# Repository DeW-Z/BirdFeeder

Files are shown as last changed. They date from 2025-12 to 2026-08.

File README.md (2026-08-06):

# BirdFeeder

BirdFeeder is a DIY bullet feeder for progressive reloading presses. Bulk projectiles are placed into the hopper, where the rotating collator plate orients them and feeds them into a drop tube leading to the press.

The project was designed around commonly available hardware, a NEMA 17 stepper motor, 3D-printed components, and a custom motor-control PCB.

## Project Status

BirdFeeder currently has two controller options:

| Option | Status |
| --- | --- |
| Original Controller | Stable and supported |
| Smart Controller | Active development |
| Planetary Gearbox | Beta testing |
| NEMA 23 Version | Beta testing | 

## Original BirdFeeder Controller

The original controller is a simple through-hole PCB that can be assembled using commonly available components.

Its main functions include:

* Adjustable stepper-motor speed
* NEMA 17 motor control
* Break-beam stopping
* Automatic restart when the feed tube clears
* Compact mounting directly on the feeder
* Quiet operation
* Mechanical slipper clutch protection

The original PCB, firmware, print files, and supporting documentation are fully open-source.

PCB manufacturing files are included in the repository and can be uploaded to a board manufacturer such as JLCPCB. These services normally require ordering several boards at once.

I will continue bulk-ordering and selling individual bare PCBs for builders who do not need a full batch. However, I am no longer producing assembled controllers or complete kits based on the original PCB.

Original PCB listing:

https://www.etsy.com/listing/4429151678/bullet-feeder-9mm-bullet-loader

## Smart Controller

The BirdFeeder Smart Controller is the newer ready-to-use controller option.

It uses an ESP32-S3 and TMC2209 stepper driver to provide easier setup, improved diagnostics, software-adjustable motor control, and electronic jam detection.

Key features include:

* Local browser-based control
* No mobile app or cloud account required
* Home Wi-Fi or standalone operation
* Physical speed-control knob
* Browser-based speed control
* Break-beam stopping and automatic restart
* StallGuard jam detection
* Adjustable jam sensitivity
* Status and diagnostic information
* Wireless firmware updates
* USB Type-C power input with compatible USB-PD supplies
* Physical start, stop, and direction controls

The controller hosts its own web interface and can function without an active internet connection.

The Smart Controller is still under active development and is not yet open-source. Hardware and firmware files will remain private until the design is further developed and tested.

Complete kits will only be offered with the Smart Controller going forward. Stock may be limited because component and manufacturing costs have increased significantly due to tariffs.

Smart Controller documentation:

[Smart Controller README](Smart%20Controller/README.md)

Smart Controller listing:

https://www.etsy.com/listing/4504139794/bullet-feeder-smart-controller

## High-Torque Testing

The standard BirdFeeder uses a NEMA 17 stepper motor and is intended to run with a reasonable amount of material in the hopper.

Some users have reported motor stalls when loading the hopper with more than approximately 100 projectiles. The exact limit varies based on:

* Projectile weight
* Collator plate design
* Printed-part friction
* Motor current
* Power-supply voltage
* Assembly alignment
* Hopper loading
* Material and print quality

Two higher-torque options are currently being evaluated.

### Planetary Gearbox

A planetary gearbox version is included as an additional MakerWorld print profile.

The gearbox increases output torque while retaining the standard NEMA 17 motor. The tradeoff is reduced output speed, additional printed components, and more mechanical complexity.

This design is currently considered beta. Builders should expect that revisions may be made as more testing and feedback are received.

### NEMA 23 Version

A separate NEMA 23 configuration is also under development.

The larger motor is intended for applications where the standard NEMA 17 does not provide enough torque, including heavier projectile types or higher-capacity configurations.

The NEMA 23 version is also considered beta and is not yet the standard recommended build.

## Hopper Capacity and Printed-Part Safety

Do not use the hopper as long-term bulk storage.

Increasing motor torque does not increase the strength of the printed hopper, mount, housing, or supporting hardware. A gearbox or larger motor may keep the collator moving, but the printed structure still supports the full static and dynamic load.

A printed part may appear to support a heavy load initially and still deform or fail after being stressed for hours, days, or weeks. This is especially important with materials that are susceptible to creep, elevated temperatures, weak layer adhesion, or insufficient wall thickness.

Recommended practices:

* Avoid filling the hopper beyond what is needed for the current loading session.
* Refill the hopper in smaller batches.
* Do not leave a heavily loaded hopper sitting between sessions.
* Use a suitable material and print orientation.
* Use adequate walls, top and bottom layers, and infill.
* Inspect the hopper, mount, motor housing, and fasteners regularly.
* Stop using any part that shows cracking, deformation, loose inserts, or damaged mounting points.

The gearbox and NEMA 23 versions are intended to address torque-related stalls. They should not be interpreted as approval to place unlimited weight in the hopper.

## Files and Documentation

The repository includes:

* Original PCB manufacturing files
* Original controller firmware
* Wiring and assembly documentation
* Smart Controller documentation
* Supporting images and reference material

3D-printable files and print profiles are hosted on MakerWorld:

https://makerworld.com/en/models/1252671-bullet-feeder-reloading-assistant#profileId-1697707

## Open-Source Status

### Currently Open-Source

* Original BirdFeeder mechanical design
* Original controller PCB
* Original controller firmware
* Manufacturing files
* Assembly documentation

### Not Yet Open-Source

* Smart Controller PCB design
* Smart Controller production files
* Smart Controller firmware source

The Smart Controller remains under active development. Its source files may be released later, but no release date is currently being promised.

## Safety

BirdFeeder is a DIY project and should be treated as experimental equipment.

Always inspect wiring, printed parts, motors, power supplies, sensors, and mechanical components before use. Do not operate the system unattended. Stop operation immediately if you notice overheating, damaged wiring, unusual noises, binding, cracked printed parts, or repeated motor stalls.

The builder and user are responsible for verifying that their completed assembly is appropriate for their equipment and intended use.

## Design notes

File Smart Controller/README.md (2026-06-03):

# BirdFeeder Smart Controller PCB

<p align="center">
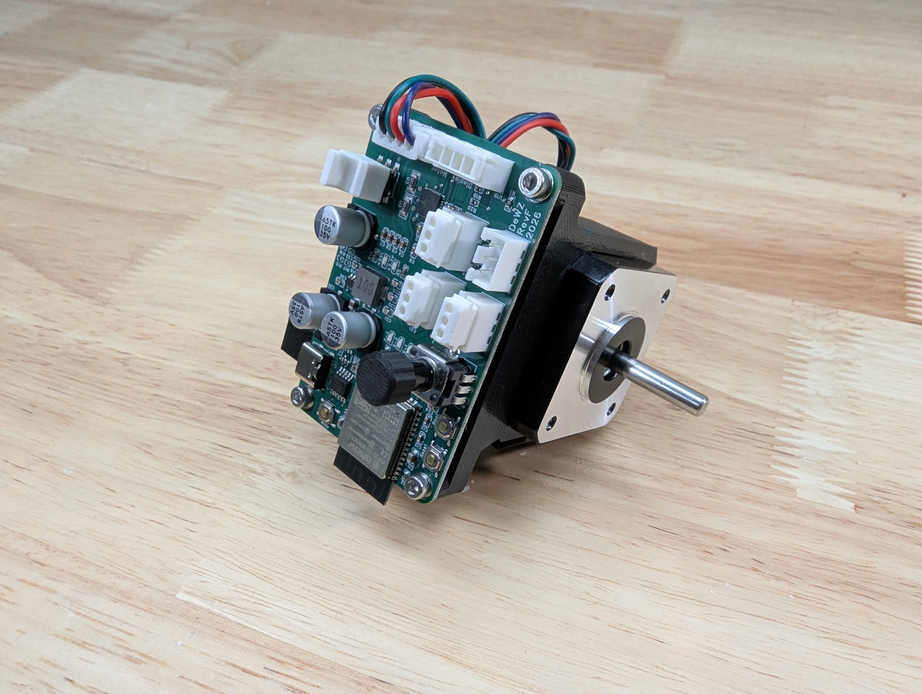
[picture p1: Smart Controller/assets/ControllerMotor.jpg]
BirdFeeder Controller
  
</p>

The **BirdFeeder Smart Controller** is the next generation of stepper motor controller for your BirdFeeder Bullet Feeder. Designed to work with standard USB Type-C power supplies (utilizing up to 20V with compatible PD plugs), it features standard connections for your Break-Beam sensor, Speed Adjuster, and Stepper Motor. 

The biggest change? **Built-in Wi-Fi.** If you are thinking, *"Great, another Wi-Fi device,"* we felt the same way at first! But after helping many people get the original PCB up and running, the biggest hurdle was always downloading complex software (Arduino IDE, drivers, and libraries) just to get started or push a simple update. 

The Smart Controller solves this. **You do not need any development tools or technical experience.** You can configure, control, update, and diagnose your feeder entirely through a simple web page on your phone or computer. It functions 100% offline, no internet access, mobile apps, or cloud accounts required.

Your controller will arrive ready to go, right out of the box!

---

##  Safety & Development Status

> 🛑 **Experimental Hardware Disclaimer:** This controller is currently considered a development and evaluation board. While it includes multiple safety and fault-detection features (such as break-beam stopping, jam detection, motor disable logic, and status monitoring), it has not been certified or evaluated as a commercial safety-rated control system. 
>
> Treat this as experimental hardware. Do not rely upon this controller for life safety, fire prevention, equipment protection, or unattended long-term operation. Do not leave the system operating entirely unattended. Always supervise operation during testing, tuning, and calibration.
>
> **Users are responsible for:** Providing appropriate power protection/wiring, ensuring the mechanism is mechanically safe, and inspecting the system regularly for wear or overheating.

---

##  Table of Contents
1. [Quick Start Guide](#-quick-start-guide)
2. [Main Features](#-main-features)
3. [Smart Controller Mount Installation](#%EF%B8%8F-smart-controller-mount-installation)
4. [Using the Web Control Page](#-using-the-web-control-page)
5. [Troubleshooting & Common Fixes](#-troubleshooting--common-fixes)
6. [Safety & Development Status](#%EF%B8%8F-safety--development-status)
7. [Advanced Technical Reference](#-advanced-technical-reference)

---

##  Quick Start Guide
*Ready to get going? Follow these simple steps to get up and running in less than 5 minutes.*

<p align="center">
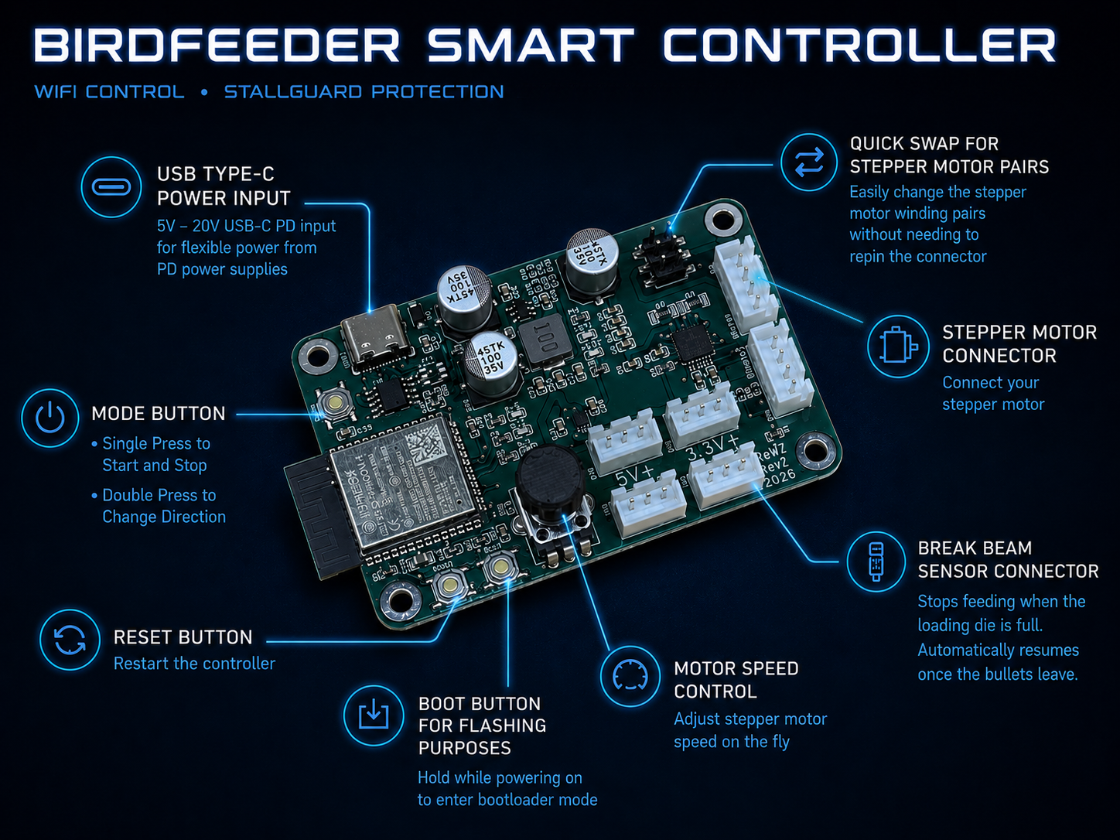
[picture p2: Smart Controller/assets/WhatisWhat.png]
Hardware Layout Map
  
</p>

### Step 1: Plug Everything In
Connect your stepper motor and Break-Beam sensor to the board as shown in the diagram above. Then, plug in your USB Type-C power supply and wait a few seconds for the board to boot up.

### Step 2: Connect to the Setup Wi-Fi
On your phone, tablet, or computer, open your Wi-Fi settings and look for a new network:
* **Network Name (SSID):** `BirdFeeder Setup`
* **Password:** `12345678`

### Step 3: Open the Web Page
Open your favorite web browser (Safari, Chrome, Edge, etc.) and type this exact address into the top URL bar:
**[http://192.168.4.1](http://192.168.4.1)**

### Step 4: Choose Your Mode
The setup screen will guide you through your choice:
* **Home Wi-Fi Mode:** Connect the feeder to your home network so any device in your house can control it. Once connected, your permanent address will be: **[http://birdfeeder.local](http://birdfeeder.local)**
* **Standalone Mode:** Keep it independent. Use this if your feeder is in a garage or workshop without Wi-Fi. You will simply connect directly to the `BirdFeeder Setup` network whenever you want to change settings.

### Don't want to use the Smart Features?
A single press of the "Mode" button will start the motor. A double press with change the direction of travel. Speed can be adjusted manually using the control knob.

---

##  Main Features

* **Easy Web Control Panel:** Control your feeder directly from a simple web page served right from the controller. Includes light and dark themes!
* **Smart Jam Protection:** Powered by built-in StallGuard technology. The controller automatically senses if the motor gets stuck and stops instantly to protect your hardware.
* **Automatic Resume:** Once the die is full of bullets, the motor stops instantly. As soon as the beam is cleared, it starts right back up on its own once the bullets drop down far enough.
* **Wireless Updates:** Easily update your controller's software with a single click right from your browser page—no cords or software installations required.
* **Dual Speed Control:** Switch between using a physical adjustment knob on the box or a digital slider on your phone screen.
* **Local Physical Button:** A single press on the built-in box button starts/stops the motor; a quick double-press reverses the motor direction.

---

##  Smart Controller Mount Installation

<p align="center">
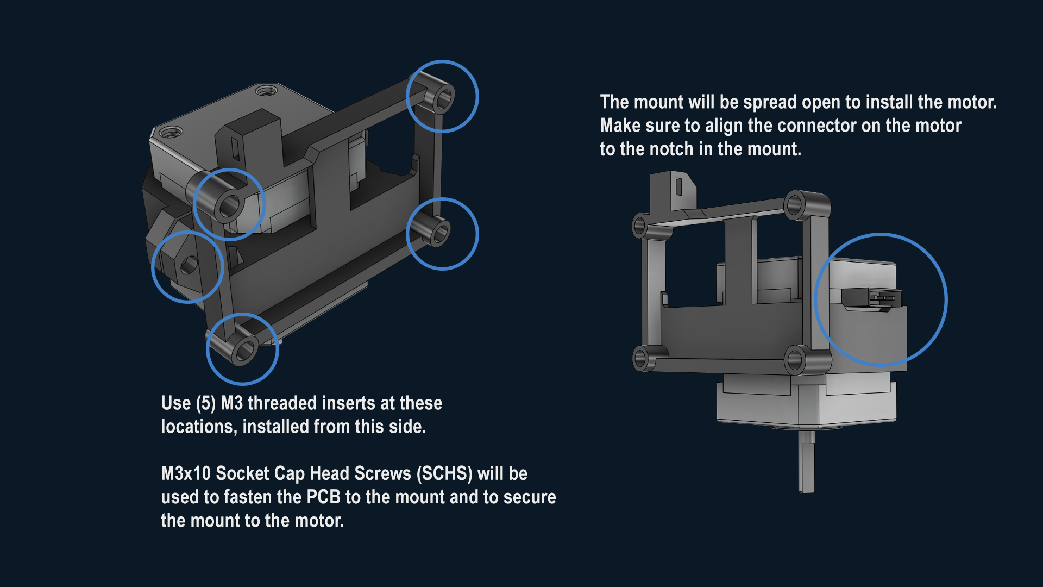
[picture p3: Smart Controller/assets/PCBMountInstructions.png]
Mounting Instructions
  
</p>

---

##  Using the Web Control Page

<p align="center">
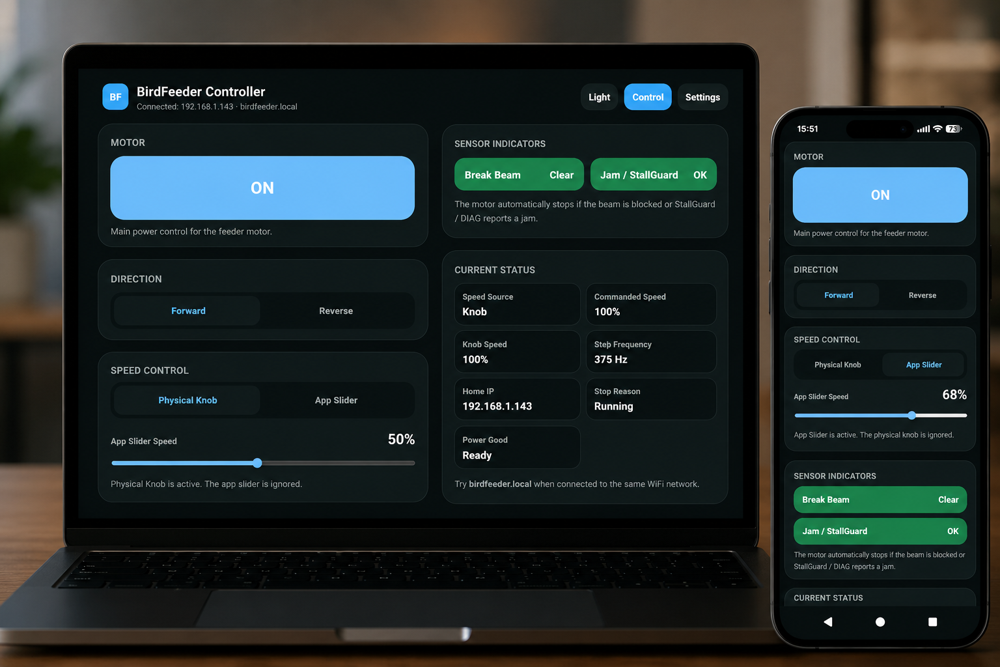
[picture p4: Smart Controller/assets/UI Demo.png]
Web Interface Demo
  
</p>

### Motor On / Off & Direction
* The large **ON/OFF** button acts as your primary toggle. 
* The direction switch toggles between **Forward** and **Reverse**. The system is pre-configured so that "Forward" matches standard feeder operations.

### Speed Control Options
Under the settings, you can pick how you want to control the speed:
1. **Physical Knob:** The controller reads the physical dial on the board. The slider on your phone screen will be ignored.
2. **App Slider:** The physical knob is ignored, and you can slide your finger across the web page to adjust speed from 0% to 100%.

### Tuning the Jam Protection (StallGuard)
Because different motors and feeder setups have different amounts of mechanical friction, you can calibrate your jam sensitivity directly from the settings page:
1. Temporarily turn off the **StallGuard Monitor** switch if it is stopping too easily.
2. Spin the feeder freely at the speed you intend to use most often.
3. Click **1. Capture Free Spin**.
4. Lightly block or add a drag load to the feeder mechanism in a controlled way to simulate a jam.
5. Click **2. Capture Jam & Apply**.
6. Turn the **StallGuard Monitor** back on and test it!

---

##  Troubleshooting & Common Fixes

###  Power & Wi-Fi Issues
* **The "BirdFeeder Setup" network isn't showing up:** Confirm the board is getting power. Wait at least 10 seconds after plugging it in. Try moving closer to the controller.
* **Connected to the Wi-Fi, but the page won't load:** Make sure you typed `http://192.168.4.1` exactly (not `https`). If using a smartphone, temporarily turn off your Cellular Mobile Data, as some phones refuse to load local setup pages if they detect no internet connection.
* **`birdfeeder.local` won't open on my home network:** Make sure your phone/computer is on the exact same Wi-Fi network as the controller. Some home routers do not support `.local` names properly. If this happens, use the specific IP address numbers shown on your initial setup confirmation page.

###  Motor Issues
* **The motor is vibrating, buzzing, or twitching instead of spinning:** This is a common issue when internal motor wires are reversed. **You do not need to cut wires!** Power off the controller and look for the small **Phase Swap Jumper** (a 3x2 set of pins) on the board. Move the jumper to the opposite position, power back on, and try again. 
* **The motor stops running as soon as I turn up the speed:** The jam protection is likely too sensitive for your high-speed settings. Try running the **StallGuard Calibration** steps at that specific high speed, or slightly increase the "trip confirmation time" in the motor tuning section.
* **The motor won't turn on at all:** Check your main control screen. Look at the **Stop Reason** readout. It will tell you if the system is waiting on a blocked Break-Beam sensor, a latched Jam alarm, or a power supply issue.

---

##  Advanced Technical Reference

### Can I build this board myself?
The design is mostly composed of **0402 SMD components** and other micro-sized parts. Hand-soldering these reliably is extremely difficult without proper hot-air reworking equipment and small SMD experience. It will eventually be open-source; once files are released, we recommend ordering pre-assembled boards via services like JLCPCB's PCBA service (usually a minimum quantity of 5 boards). The original legacy manual PCB remains available for those who prefer classic through-hole hand-soldering.

### Status LEDs & Meaning
| Indicator | Meaning | Normal State | Fault / Alert State |
| :--- | :--- | :--- | :--- |
| **Motor / Running** | Shows if the motor is enabled | ON when spinning | OFF when stopped |
| **Break-Beam** | Shows sensor block status | Clear / Off | ON when beam is actively blocked |
| **Jam / StallGuard** | Shows hardware jam fault status | OFF (OK) | ON when a jam fault is active/latched |

### Default Settings & Tuning Metrics
| Setting | Default Value | Purpose |
| :--- | :--- | :--- |
| **Min STEP Speed** | 25 Hz | Lowest step frequency used above 0% speed |
| **Max STEP Speed** | 375 Hz | Highest step frequency at 100% speed |
| **Acceleration** | 4000 steps/s² | How quickly the motor ramps up to speed |
| **StallGuard Confirm** | 50 ms | How long a jam must stay active before stopping |
| **Sensitivity (SGTHRS)**| 25 | TMC2209 driver register setting |
| **Min SG Detect Speed** | 100 Hz | Below this speed, StallGuard is completely ignored |

### Useful Local API Paths
The controller hosts its own local endpoints. These can be queried via JSON or used for automation:
* `/` — Main control page interface.
* `/settings` — Advanced configuration, diagnostics log, and OTA firmware updater.
* `/api/status` — Returns full device status metadata as JSON.
* `/api/resetOnboarding` — Clears memory to re-trigger the initial setup welcome popup.
* `/api/reboot` — Gracefully power-cycles the ESP32-S3 microcontroller.

### Documented Reference Firmware
* **Version:** `1.0.15 - 05.11.2026`
* **Processor Architecture:** ESP32-S3 Core / TMC2209 Stepper Driver via UART Address 0.

### Getting Support
If you encounter unexpected behavior and need help troubleshooting, please provide the following information when reaching out:
1. Firmware version and network mode (Home Wi-Fi vs. Standalone).
2. The exact **Stop Reason** shown on the control page.
3. Status indicators (Break-Beam clear/blocked, Jam OK/jammed).
4. Current step frequency and speed percentages.
5. TMC UART status and a copy/screenshot of the **Device Log** found on the settings page.

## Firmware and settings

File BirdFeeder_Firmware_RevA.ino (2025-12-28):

#include <Arduino.h>
#include <TMCStepper.h>
#include <SoftwareSerial.h>

#define RMS_VALUE                1350   // SET YOUR MOTORS AMPERAGE HERE IN mA. 1350 = 1.35amps. RECOMMEND 80% OF LISTED VALUE.
#define REVERSE_DIRECTION        0      // Set to 1 to reverse direction, 0 for normal direction
#define ENABLE_STALL_HANDLING    0      // **BETA** Set to 1 to enable, 0 to disable
//
//////// EDIT BELOW THIS AT YOUR OWN RISK. DAMAGE MAY OCCUR. ////////
//
#define TOFF_VALUE               4
#define stallPin                 7
#define EN_PIN                   12
#define SW_RX                    9
#define SW_TX                    8
#define statusPin                4
#define breakBeamPin             2
#define accPin                   6
#define speedAdj                 A1
#define DRIVER_ADDRESS           0b00
#define RESET_DELAY              5000
#define R_SENSE                  0.11f
#define STALL_VALUE              0
#define SG_THRESHOLD             3
#define MAX_COUNT                3
#define TIME_PERIOD              1000
unsigned int stallCount = 0;
unsigned long lastCheckTime = 0;

SoftwareSerial SoftSerial(SW_RX, SW_TX);

TMC2209Stepper driver(&SoftSerial, R_SENSE, DRIVER_ADDRESS);

using namespace TMC2209_n;

void setup() {
  Serial.begin(115200);
  while(!Serial);
  driver.beginSerial(115200);
  SoftSerial.begin(115200);

  pinMode(statusPin, OUTPUT);
  pinMode(stallPin, INPUT);
  pinMode(breakBeamPin, INPUT_PULLUP);
  pinMode(accPin, INPUT);
  pinMode(statusPin, OUTPUT);
  pinMode(EN_PIN, OUTPUT);
  digitalWrite(statusPin, HIGH);
  digitalWrite(EN_PIN, LOW);
 

  driver.begin();
  driver.intpol(true);
  driver.en_spreadCycle(0);
  driver.toff(TOFF_VALUE);
  driver.blank_time(24);
  driver.rms_current(RMS_VALUE);
  driver.mstep_reg_select(true);
  driver.microsteps(4);
  driver.TCOOLTHRS(0xFFFFF);
  driver.semin(5);
  driver.semax(2);
  driver.sedn(0b01);
  driver.SGTHRS(STALL_VALUE);
  driver.pdn_disable(true);
}

void loop() {
  digitalWrite(statusPin, LOW); 
  digitalWrite(EN_PIN, LOW);
  // int statusPinState = digitalRead(statusPin);
  // Serial.print("Status Pin (4) is currently: ");
  // Serial.println(statusPinState == HIGH ? "Error" : "System Good");

  int breakBeamState = digitalRead(breakBeamPin);

  static unsigned long lastPrint = 0;
  if (millis() - lastPrint > 500) {
    // Serial.print("Sensor Pin (2) is currently: ");
    // Serial.println(breakBeamState == HIGH ? "Sensor not blocked" : "Sensor Blocked");
    lastPrint = millis();
  }

  if (breakBeamState == LOW) { 
    handleBreakBeam();
    return; 
  }

  int potValue = analogRead(speedAdj);
  int mappedValue = map(potValue, 0, 1023, 0, -100);
  #if REVERSE_DIRECTION
    mappedValue = -mappedValue;
  #endif
  driver.VACTUAL(mappedValue);
}

void handleBreakBeam() {
  driver.VACTUAL(0);
  Serial.println("Motor stopped: BEAM BROKEN");
  flashStatusPin(1, 250); 
}

void handleStall() {
  driver.VACTUAL(0);
  Serial.println("Motor stopped: JAM DETECTED");
  flashStatusPin(10, 50);
  digitalWrite(EN_PIN, HIGH);
  delay(1000);
  digitalWrite(EN_PIN, LOW);
}

void flashStatusPin(int times, int delayTime) {
  for (int i = 0; i < times; i++) {
    digitalWrite(statusPin, LOW);
    delay(delayTime);
    digitalWrite(statusPin, HIGH);
    delay(delayTime);
  }
}

//Serial.println(getDiagnosticInfo());
String getDiagnosticInfo() {
  int breakBeamState = digitalRead(breakBeamPin);
  String info = "Diag Status: ";
  info += digitalRead(stallPin);
  info += " ";
  info += driver.cs2rms(driver.cs_actual()), DEC;
  info += " ";
  info += driver.SG_RESULT(), DEC;
  info += "       ";
  info += driver.SGTHRS();
  info += " ";
  return info;
}
  

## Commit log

2023-08-17 F3D File with Hand Turn
    [Bullet Feeder - 9mm v15.f3d]
2023-08-17 Bullet Feeder with Hand Turn - STEP
    [Bullet Feeder - 9mm v15.step]
2025-07-15 Delete Bird Feeder Assembly Manual.pdf
    Replaced with V2.
2026-05-13 Update fmt.Println message from 'Hello' to 'Goodbye'
2026-08-06 Revise README for BirdFeeder project details
    Updated README to provide detailed information about the BirdFeeder project, including assembly instructions, controller options, and safety guidelines.
